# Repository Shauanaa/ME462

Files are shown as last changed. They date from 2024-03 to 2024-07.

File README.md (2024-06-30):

# 🏒 AirHockey and Micro Robot Project
istockphoto-1455938819-612x612 (1)

## 📚 Table of Contents
- [Project Abstract](#project-abstract)
- [AirHockey](#airhockey)
  - [Mechanical](#mechanical)
  - [Software](#software)
  - [Electronic](#electronic-airhockey)
- [Micro Robot](#micro-robot)
  - [Mechanical](#mechanical-1)
  - [Software](#software-1)
  - [Electronic](#electronic-microrobot)
- [How to Use the Code](#how-to-use-the-code)
- [Cautions](#cautions)
- [Contribution](#contribution)
- [License](#license)

## 🎯 Project Abstract
This project integrates an IoT-enabled air hockey table with a remotely controllable micro robot, creating diverse game scenarios. It showcases the fusion of mechanical engineering and software development to produce an interactive, entertaining system that reimagines classic gameplay through modern technology.

## 🏒 AirHockey

### Mechanical
The skeleton of the hockey table is constructed using a robust framework of aluminum extrusions, providing both strength and versatility. The main structure utilizes 20x20 mm sigma profile extrusions, offering an excellent balance of lightweight design and structural integrity. For enhanced stability and support, particularly along the edges, 20x40 mm extrusions are employed for the top bars, ensuring a rigid and durable frame.

The table's playing surface is crafted from high-quality plexiglass, chosen for its smooth texture and durability. This surface is meticulously perforated with 1 mm diameter holes arranged in a precise grid pattern. These holes serve a crucial function in the air hockey system, allowing for even air distribution across the entire playing field, which is essential for smooth puck movement.

To contain the gameplay and provide a clean aesthetic, the sides of the table are enclosed using medium-density fiberboard (MDF). This material was selected for its cost-effectiveness, ease of fabrication, and ability to be finished smoothly. The MDF side panels not only define the boundaries of the playing area but also contribute to the overall structural integrity of the table.

The entire assembly is held together using a combination of M5 and M6 screws and nuts. This hardware selection ensures a secure connection between all components while allowing for potential disassembly or modifications in the future. The use of standardized fasteners also simplifies maintenance and repairs.
This thoughtful design and material selection results in a hockey table that is not only sturdy and functional but also aesthetically pleasing and adaptable to various gameplay modifications or technological integrations.

There is a 'balcony' under the fans which is a housing for electronic components.

Our air hockey table is equipped with:

- High-powered air blowers
- High energy power supply for LEDS 
- Camera setup for object detection/tracking 
- LED lighting system for enhanced gameplay experience
- Remotely controllable side obstacles 

### Software
The software interfaces with 13 NeoPixel LED lines, strategically positioned and serially connected around the table. These LEDs are carefully wired and soldered to ensure stable connections between the power supply and each LED, enabling dynamic lighting effects during gameplay.

Complementing the LED system are mini electronic side obstacles, each equipped with its own controller. These obstacles are connected using jumper wires and breadboards, allowing for independent operation and easy modifications. This modular approach facilitates maintenance and potential future upgrades.

The combination of serially connected LED lines and independently controlled obstacles creates a flexible and responsive gaming platform, capable of supporting various gameplay scenarios and interactive features.

The air hockey system is powered by:

- Computer vision algorithms for real-time puck and leds
- Pip installable python code: `pip install air-hockey`
- ROS2 integrated software
  
### Electronics
- Please see the readme.md document [here](https://github.com/Shauanaa/ME462/blob/main/03_Codes/01_Air_Hockey/README.md)

## 🤖 Micro Robot

### Mechanical

The micro robot's chassis is additively manufactured using Creality 3D printers, offering a lightweight yet durable design. The chassis is engineered to house and protect all electronic components from external damage. Two strategically positioned motors control the robot's movement, enabling precise maneuvering and agile performance on the air hockey table. This combination of 3D-printed structure and dual-motor system results in a compact, resilient robot capable of swift and accurate movements during gameplay.

The micro robot features:

- Compact, agile design for quick movements
- Remotely Controllable motors
- Durable chassis to withstand impacts
- Modular design for easy maintenance and upgrades

### Software
The micro robot features two motors controlled by an ESP8266 microcontroller. An ESP-NOW controller enables remote control of the micro-robots, allowing for precise maneuvering. Additionally, the robot is equipped with a controllable propeller, enhancing its movement capabilities. This combination of dual-motor drive, wireless control, and propeller system creates a versatile and responsive robot, ideal for dynamic air hockey gameplay.

The micro robot is controlled by:

- You by publishing a message to the relevant topic, Raspberry Pi communicating with a controller ESP8266 via serial communication to send commands, controller ESP communicating with the micro robot ESP8266 using ESP-NOW protocol, and finally, the micro robot ESP applying the command.
### Electronics
- The schematics of the microrobot are provided as following:
  MicroRobotCircuit_bb (1)
- More technical drawing is as follows:
   MicroRobotCircuit_schem (1)

## 🖥️ How to Use the Code

Each entity in this project has its own readme file in details. HEre's the quick introduction version.
The folder structure is descripted as below:
```
project_root/
│
├── /03_Codes
│   └── 01_Air_Hockey/
│       ├── python_api/
│           └── microrobot_commander.py
│           ├── neopixel_controller.py
│       ├── ros2_ws/
│           └── src/air_hockey/
│               └── air_hockey/
│                   └── __init__.py
│                   ├── commander.py
│                   ├── commander_demo.py
│                   ├── localize.py
│                   ├── neopix.py
│                   ├── neopixel_demo.py
│               ├── config/
│                   └── cam_params.yaml
│               ├── resource/
│                   └── air_hockey
│               ├── test/
│                   └── test_copyright.py
│                   ├── test_flake8.py
│                   ├── test_pep257.py
│               ├── LICENSE
│               ├── package.xml
│               ├── setup.cfg
│               ├── setup.py
│           ├── 99-gpio.rules
│           ├── neopixel_test.py
│           ├── requirements.txt
│           ├── README.md
|       ├── qr_code_label_and_centroid_detection.py
│       └── camera_controller.py
│       └── Readme.md
│   └── 02_Micro_Robot/
|       ├── esp8266_espnow/
│           └── esp8266_espnow.ino
│       └── esp8266_espnow_agents/
│           └── esp8266_espnow_agents.ino
│           └── motor.ino
│       └── Readme.md

```

To get started with the AirHockey and Mini Robot project, follow these steps:

#### 1. Clone the Repository
```
git clone https://github.com/Shauanaa/ME462.git
cd ME462
```

#### 2. Install Dependencies
Ensure you have Python installed, then run:
```
pip install -e .
```

#### 3. Configure the System
##### For Python API:
  1) Install the requirements : `pip install neopixels serial numpy`
##### For ROS2:
  1) Create a venv: `python3 -m venv ~/ros2_venv`
  2) activate the venv `source ~/ros2_venv/bin/activate`
  3) install the required packages `pip install rclpy neopixels board serial`

#### 4. Run the Air Hockey System
##### For Python API:
  1) Install the requirements : `pip install neopixels serial numpy`
  2) Then simply run the codes: `python microrobot_commander.py` and `python neopixel_controller.py
##### For ROS2:
  1) navigate to the venv `cd ~/ros2_ws`
  2) Build your workspace: `colcon build`
  3) activate the venv `source ~/ros2_venv/bin/activate`
  
#### 5. Control the Micro Robot
Run the desired codew as folloing:`ros2 run air_hockey <package_name>`

#### 6. Additional Commands
- To segment the leds from the camera image : `python led_finder.py`
- To detect the QR code labels of the robots and positions of them: `python qr_code_label_and_centroid_detection.py`
- To test neopixels in ROS2: `python 03_Codes/01_Air_Hockey/ros2_ws/src/air_hockey/air_hockey/neopixel_demo.py`
- To test commander tools in ROS2: `python 03_Codes/01_Air_Hockey/ros2_ws/src/air_hockey/air_hockey/commander_demo.py`

For more detailed instructions and troubleshooting, please reach out the contributors and open an issue.

## ⚠️ Cautions

When using this system, please be aware of the following:
- 🛑PLEASE UNPLUG ALL OF THE CABLES WHILE OPENING THE ELECTRONIC DEVICES OF THE AIRHOCKEY TABLE🛑

- The IP address of the Raspberry Pi changes when connecting to different networks. Always ensure you have the correct IP address before attempting to connect to the Raspberry Pi.
- Do not forget to change the shebang of the ROS2 codes such that it points to a python interpreter on your system.

## 🤝 Contribution

We welcome contributions from the community! If you'd like to contribute, please follow these steps:

1. Fork the repository
2. Create your feature branch (`git checkout -b feature/AmazingFeature`)
3. Commit your changes (`git commit -m 'Add some AmazingFeature'`)
4. Push to the branch (`git push origin feature/AmazingFeature`)
5. Open a Pull Request

## 📄 License

This project is licensed under the MIT License - see the [LICENSE.md](LICENSE.md) file for details.

---

<p align="center">
  Made with ❤️ by the AirHockey and Mini Robot Team:
  Berk Ünlü, 
  Sait Burak Yücekaya,
  Yunus Çınar Kızıltepe,
  Tan Çağatay Acar,
  Doğukan Özoğul,
  Candaş Uysal
</p>

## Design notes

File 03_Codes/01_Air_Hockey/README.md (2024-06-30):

# Air Hockey
The codes that run on the Raspberry Pi of the air hockey table. The Raspberry Pi has Ubuntu 24.04 Server running.

### Python API
#### NeoPixel Controller
Python library to control NeoPixels of the air hockey table. Example usage:
```
from air_hockey.neopixel_controller import NeoPixel_Controller

controller = NeoPixel_Controller()

controller.fill((100, 0, 255)) # Set every pixel the specified rgb color.

controller.setFromFlatArray([(100, 0, 255),(80, 20, 255),(60, 40, 255),(40, 60, 255),(20, 80, 255),(0, 100, 255)]) # Sets pixels from array in order.
```
#### Commander
Python library to control micro robots wirelessly. Desk fan example:
```
from air_hockey.microrobot_commander import Commander
import time,math

commander = Commander()
theta = 0
while True:
    mag = 80*math.sin(theta)
    commander.send(1, int(mag), int(-mag), 200)
    theta = theta + 0.15
    time.sleep(0.1)
```
#### Localization
Python library to obtain pose data of micro robots. Example usage:
```
from air_hockey.localize_microrobot import Locator
import time

locator = Locator()
while True:
    print(locator.getPoses())
    time.sleep(0.5)
```
### ROS2 Workspace
This workspace contains the `air_hockey` package that includes the codes to be able to control LEDs of the table, control micro robots and obtain the pose information of these robots.
#### NeoPixels
The server code is run by the command `ros2 run air_hockey neopixel`. This code listens to 2 topics called `/NeoPixel/array` and `/NeoPixel/fill`. They show the given rgb array or all LEDs display a RGB color, respectively. Array elements are 8-bit unsigned integers and mimic OpenCV Numpy Array structure. Fill topic communicates with `std_msgs/msg/ColorRGBA` and expects float values that range from 0.0 to 1.0.
#### Commander
The commander code is run by the command `ros2 run air_hockey commander`. This code listens to `/agent_0/cmd` and `/agent_1/cmd` topics. These topics expect 3 integer values: left motor power, right motor power, and fan motor power, respectively. These values are in ranges {[-255,255],[-255,255],[0,255]}. This code then communicates with the commander ESP that controls the micro robots.
#### Localization
The localization code is run by the command `ros2 run air_hockey localization`. This code uses the camera to detect the April Tags of the micro robots and calculate their poses. Once detected, the pose data are published to `/agent_x/pose` topic, where x changes with the detected tag id.

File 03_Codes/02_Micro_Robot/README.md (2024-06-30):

# Micro Robot
This robot is a small, remote controllable, heavy robot that is also equiped with a fan. Controlling these robots remotely is not explained here and instead discussed in [Air Hockey Section](/03_Codes/01_Air_Hockey).

### Mechanics
The mechanical design of the robots are completed with Autodesk Fusion. Therefore, Fusion Archive Files and stls are included in [this folder](/04_CAD_Files/02_Micro_Robot).
#### April Tags
These robots can have April Tags on them to have localization features. Tag standart 36h11 is used with size 56 mm. You can use [this website](https://chaitanyantr.github.io/apriltag.html) for easy tag generation. You should use tags with ids the same with the agents'.

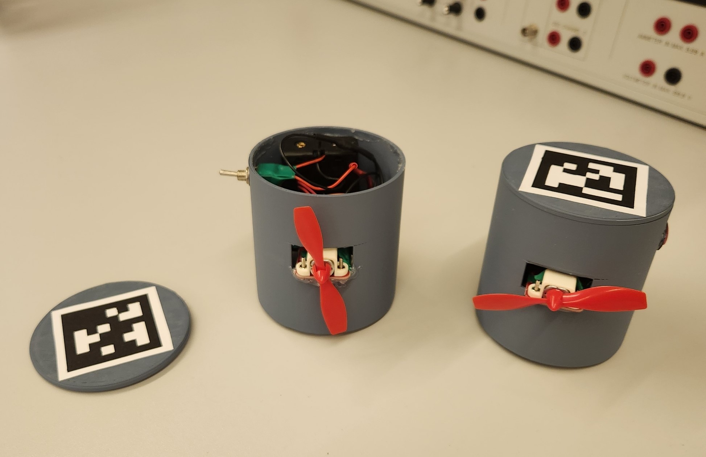
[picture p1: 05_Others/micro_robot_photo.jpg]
Micro Robots


### Electronics
The electonics are fitted in such a small compartment that we need the smallest components and modules to construct this robot. The list of the components used to build one robot is provided [here](/04_CAD_Files/02_Micro_Robot/MicroRobotCircuit_bom.html):

* [L9110 Fan Module](https://www.robolinkmarket.com/l9110-fan-modulu)
* [2x70 RPM 12mm Micro Motor](https://www.robotistan.com/6v-12mm-70-rpm-reduktorlu-dc-motor)
* [TB6612FNG Motor Controller](https://www.robotistan.com/tb6612fng-step-motor-surucu-dc-motor-sucuru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)
* [Lolin (Wemos) Mini Clone ESP8266 Card](https://www.robolinkmarket.com/esp8266-nodemcu-mini-gelistirme-karti)
* [2A Mini Buck Converter](https://www.robolinkmarket.com/2a-mini-ayarlanabilir-voltaj-dusurucu-regulator-karti)
* [2x18650 Li-ion Battery](https://www.robolinkmarket.com/power-xtra-px18650-25p-37v-2500-mah-li-ion-sarjli-pil-12c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)
* [2S 18650 Battery Bed](https://www.robolinkmarket.com/2li-18650-pil-yuvasi-lityum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)
* On/Off Switch
* Female Headers and Wires

The pin assignments are present in the codes provided. Also a fritzing circuit drawing can be found in [CAD folder](/04_CAD_Files/02_Micro_Robot).

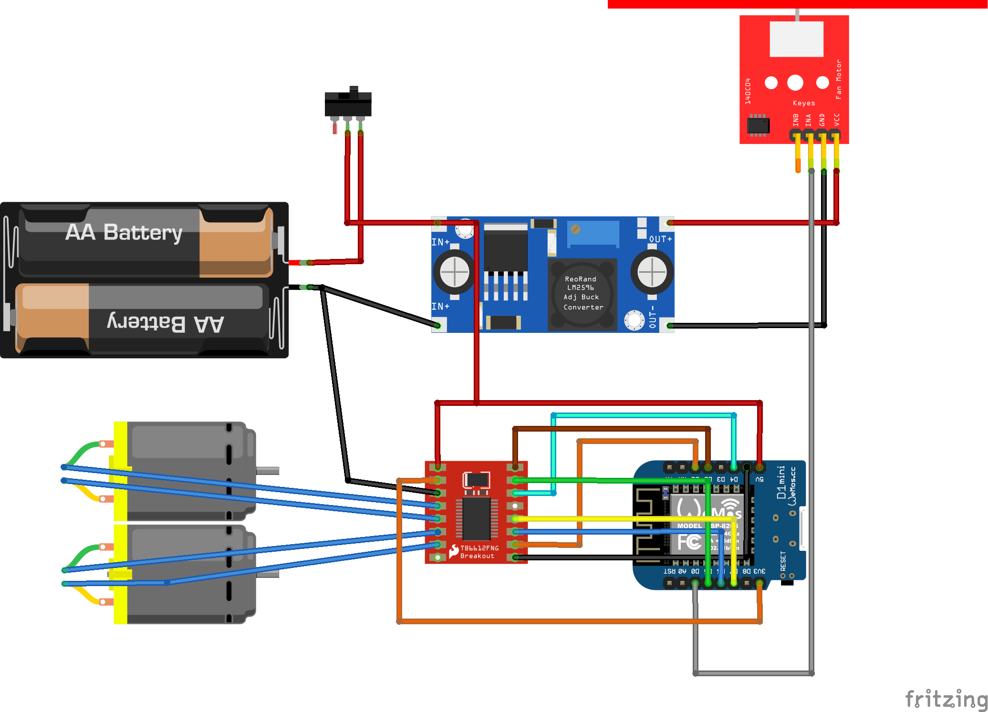
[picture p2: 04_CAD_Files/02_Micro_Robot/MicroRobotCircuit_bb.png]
Circuit Drawing


### Software
The ESP8266 microcontroller is coded with Arduino IDE. 2 codes are present, `esp8266_espnow_agents` code is for the robots. The `AGENT_ID` should be unique for each robot that will operate simultaneously. `esp8266_espnow` code is for the controller ESP8266 that is used to communicate with the robots. This controller should be connected to your PC or the Raspberry Pi via a USB cable to be able to control the robots. `MAX_AGENTS` parameter dictates the maximum number of robots to be controlled simultaneously. Also, the robots should have ids lower than this value!
#### Registering New Agents
In order for commander ESP to search and find new agents, first the new agent robots should be opened, then the commander ESP needs to be reseted. After this operation, commander saves the new agents' MAC addresses in its EEPROM so it remembers them until a different is registered with the same id.

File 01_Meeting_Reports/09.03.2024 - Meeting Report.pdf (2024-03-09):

[Air Hockey - Micro Robot Group] ME462 - TOPLANTI 1
2023-2024 BAHAR

9 Mart 2024

## 1 GUNDEM ¨

Bu dok¨ uman 9 Mart 2024 tarihinde Air Hockey - Micro Robot proje grubu arasında yapılan ¨
toplantıda tartıs¸ılan konuları ozetlemek ¨ | uzere yazılmısţır. ¨

Toplantının gundem basļıkları s¸u sȩkilde sıralanabilir. ¨

1. Mock-up mekanik dizaynın tartıs¸ılması ve gelisţirilmesi
2. Dizayn ozelinde olus¸abilecek problemlerin tespiti ve tartıs¸ılması ¨
3. Proje için ilerleyen safhalardaki isterlerin tespiti
4. Proje bazlı gorevlendirme tanımlamalarının netlesţirilmesi ve alt grupların belirlenmesi ¨
5. Alt gruplar arası iletis¸imi saglamak ˘ | uzere bir koordinat ¨ | or ¨ un seçilmesi ¨
6. Karalasţırılan grupların is¸bas¸ı yapması

### 1.1 Mock-Up Mekanik Dizaynın Tartıs¸ılması ve Gelisţirilmesi

05.03.2024 tarihinde ROMER’de yapılan toplantının ardından deneme amacļı bir CAD modelinin
tasarımı yapılmısţır ve tum¨ | uyelerin katılımıyla geli ¨ | sţirilmisţir. İlk modelimizin eksikleri tespit
edilmis¸ ve moduler tasarımın modele nasıl entegre edilebilece ¨ | gi tartı ˘ | s¸ılmısţır. Çizilen modele gore ¨
basitcȩ tahta kullanılarak pleksi levhanın sabitlenecegi bir platform ˘ | uretilmisţir. ¨

Buna ek olarak, tahtadan yapılan model ile kars¸ılasţırılmak uzere CAD modelimizin de 3D ¨
baskı yontemiyle elde edilmesi kararla ¨ | | | | sţırılmısţır. Bu kararın arkasındaki ana neden 3D parçamızın
dıs¸ında kullanabilecegimiz materyallerin duvarlarının hava ka ˘ | çırma karakteristigini test etmektedir. ˘
Baskı alabilmemiz ise farklı buy¨ ukl ¨ ukte ve sıklıkta deliklerin hava akı ¨ | s¸ındaki etkisinin belirlenmesi
de mumk ¨ | un g ¨ | oz¨ ukmesinden ¨ | ot ¨ ur ¨ u dizayn s ¨ | urecinde avantaj icȩrmektedir. ¨

### 1.2 Dizayn Ozelinde Olus¸abilecek Problemlerin Tespiti ve Tartıs¸ılması ¨

Bu noktada kars¸ılasţıgımız hatalardansa mod ˘ | uler dizayn kullanıldı ¨ | gı senaryoda olu ˘ | s¸abilecek
muhtemel problemler dus¸¨ un¨ ulm¨ us¸ ve bunların nasıl minimize edilebilece ¨ | gi tartıs¸ılmısţır. ˘
Genellikle nihai dizaynımızdaki yerles¸im problemleri (arenamızı sekizgen du¨s¸und ¨ | u¨gŭm¨ uzde ¨
kenarlara oturtmak istedigimiz istasyonların yerle ˘ | s¸imleri) ele alınmısţır. Burada mekanik ve elek-
tronik çoz¨ umler d ¨ | u¨s¸un¨ ulm¨ u¨s¸ ve birkaç fikir elde edilmisţir. Buna ek olarak istasyonların kenarlarda
olması planlanan sigma profillere monte etmek yerine arenanın içine entegre edilip edilemeyecegi ˘
dus¸¨ un¨ ulm¨ us¸, ve karar daha sonraki toplantılarda finalize etmek ¨ | uzere ertelenmisţir. ¨

ME462 - Mechatronic System Design

Arenanın elektronik dizaynı ile ilgili olarak ise olası iletis¸im protokolleri (I2C, USB Serial ve WiFi) ve bunların entegrasyonu tartıs¸ılmısţır. Çıkabilecek problemler, avantajlar ve dezavantajlar
goz¨ on¨ une alınarak mod ¨ | uler mekanik dizayn i ¨ | çin detaylı arasţırmaların yapılmasına karar verilmisţir.
Bir diger ˘ | oenmli dizayn kriteri olan g ¨ | u¨ç aktarım istasyonunun nasıl yapılabilecegi ile ilgili fikir ˘
alıs¸veris¸i yapılmısţır.

### 1.3 Proje İçin İlerleyen Safhalardaki İsterlerin Tespiti

Bu konuda gelisţirmek istedigimiz sistemimiz için gerekli isterler bulunmaya çalıs¸ılmısţır. ˘

1.4 Proje Bazlı Gorevlendirme Tanımlamalarının Netle ¨ | sţirilmesi ve Alt Gru-

### pların Belirlenmesi

Projenin basļangıcından itibaren belirsiz ve duzensiz olan g ¨ | orevlendirmeleri netle ¨ | sţirmek amacıyla
grup uyelerinin de ¨ | çalıs¸mak istedigi konular da g ˘ | oz¨ on¨ unde bulundurularak proje i ¨ | çinde alt takımlar
olusţurulmusţur.
Bu alt grupları olusţurmamızın temel amacı, her uyenin ana sorumlu olarak ¨ | çalıs¸acagı alanları ˘
spesifik olarak belirleyerek ileride kars¸ılas¸abilecegimiz olası problemleri en az hasarla atlatabilmek- ˘
tir. Ustelik bu sayede g ¨ | orev da ¨ | gılımının proje s ˘ | uresince e ¨ | s¸it dagılımı ama ˘ | cļanmaktadır. Ancak bu
ozelles¸me farklı alanların birbirinden habersiz bir sȩkilde çalıs¸aca ¨ | gı sȩklinde algılanmamalıdır. ˘

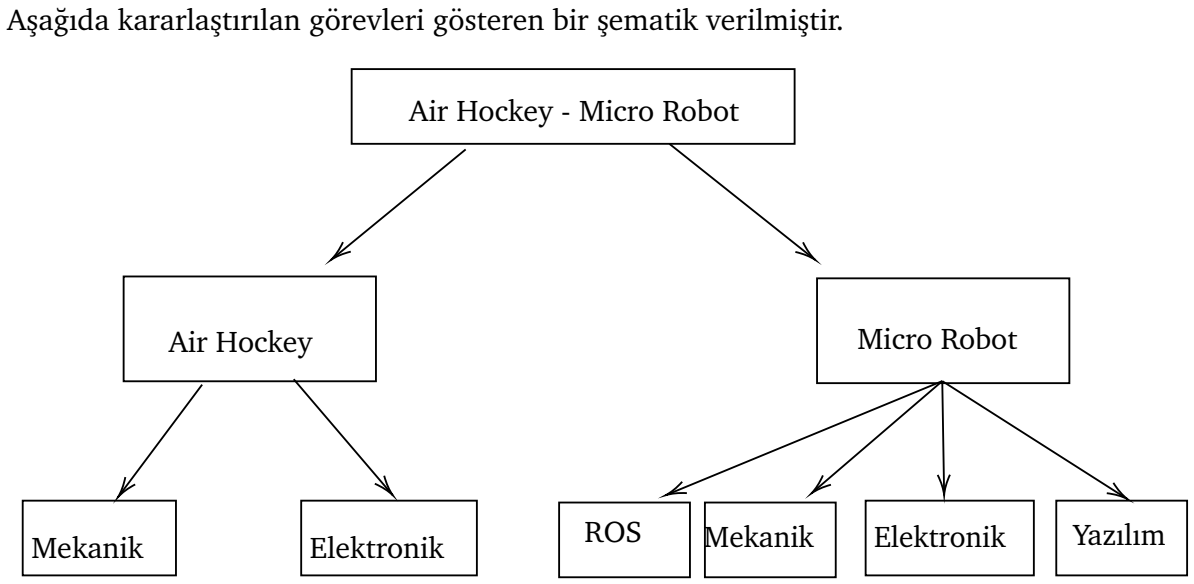
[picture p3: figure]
As¸agıda kararlasţırılan g ˘; orevleri g ¨; osteren bir sȩmatik verilmisţir. ¨; Air Hockey - Micro Robot; Air Hockey; Micro Robot; Mekanik; Elektronik; ROS; Yazılım

Candas¸

Çınar

Sait

Dogukan ˘ | Dogukan ˘
| Çınar

Berk

Sait

Sait

Candas¸

Tan

Dogukan ˘

Tan

2

ME462 - Mechatronic System Design

1.5 Alt Gruplar Arası İletis¸imi Saglamak ˘ | Uzere Bir Koordinat ¨ | or¨ un Seçilmesi ¨
Grupların ayrılması ne kadar odaklanma seviyesini ne kadar arttırsa da yarattıgı ileti ˘ | s¸imsel
sıkıntılar onemli bir dezavantaj da i ¨ | cȩrmektedir. Bu negatif etkileri minimize etmek ve her-
hangi bir kopukluk yas¸amamak uzere ¨ | uyelerden birinin gruplar arası koordinasyonu s ¨ | urd ¨ urmesi ¨
amacļanmısţır. Uyelerin ders programları ve yo ¨ | gunlukları tam olarak bilinmedi ˘ | ginden koordinat ˘ | ore ¨
daha ileri bir tarihte karar verilecektir.

### 1.6 Karalasţırılan Grupların İs¸bas¸ı Yapması

Tum hushuslar tartı ¨ | s¸ıldıktan sonra yapılacak en etkili yontemin en kısa s ¨ | urede elle tutulur bir ¨
model elde etmek ve projemizde kullanılacak kaynakların hazırlanması oldugu konusunda t ˘ | um¨
uyeler hemfikirdir. Bu sebeple, bu toplantı sonrasında iki ayrı gruba b ¨ | ol ¨ un¨ ulm¨ | u¨s¸ ve kaynakların
hazırlanmasına basļanılmısţır.
Bir grup yukarıda bahsedildigi ˘ uzere de mekanik olarak ¨ | uretimle ba ¨ | sļamıs¸ ve iki ayrı materyalden
model elde edilmeye çalıs¸ılmısţır.
Diger grup ise Micro Robot kolunda kullanılacak Raspberry Pi 4 mikrokontrolc ˘ | us ¨ un¨ un kamera ¨
entegrasyonu konusunda çalıs¸malarda bulunmusţur. Bu çalıs¸malarda kameranın Raspberry Pi 4
mikrokontrolcus ¨ un¨ un i ¨ sļetim sistemi Ubuntu Jammy Jellyfish 22.04 yardımıyla kontrolu denenmi ¨ | sţir.
Son olarak da ROS sisteminin mikrokontrolcude çalıs¸ıp çalıs¸madı ¨ | gı g ˘ ozlenmisţir. ¨

3

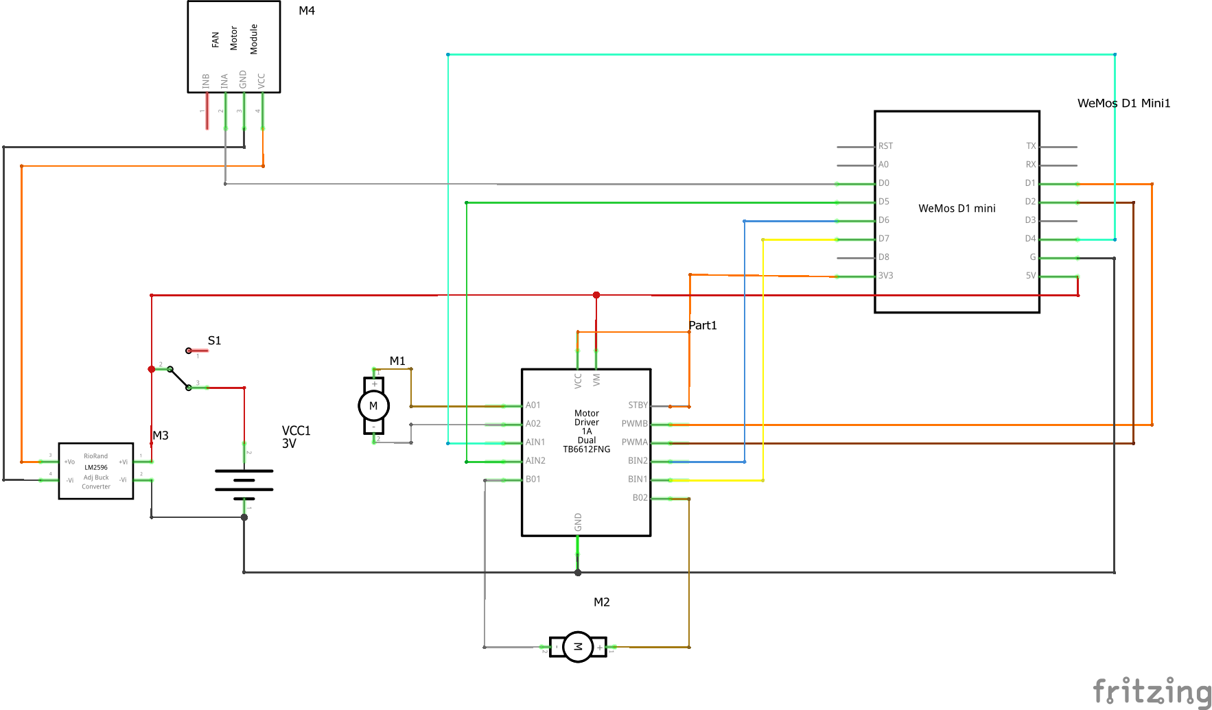
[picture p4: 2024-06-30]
04_CAD_Files/02_Micro_Robot/MicroRobotCircuit_schem.png

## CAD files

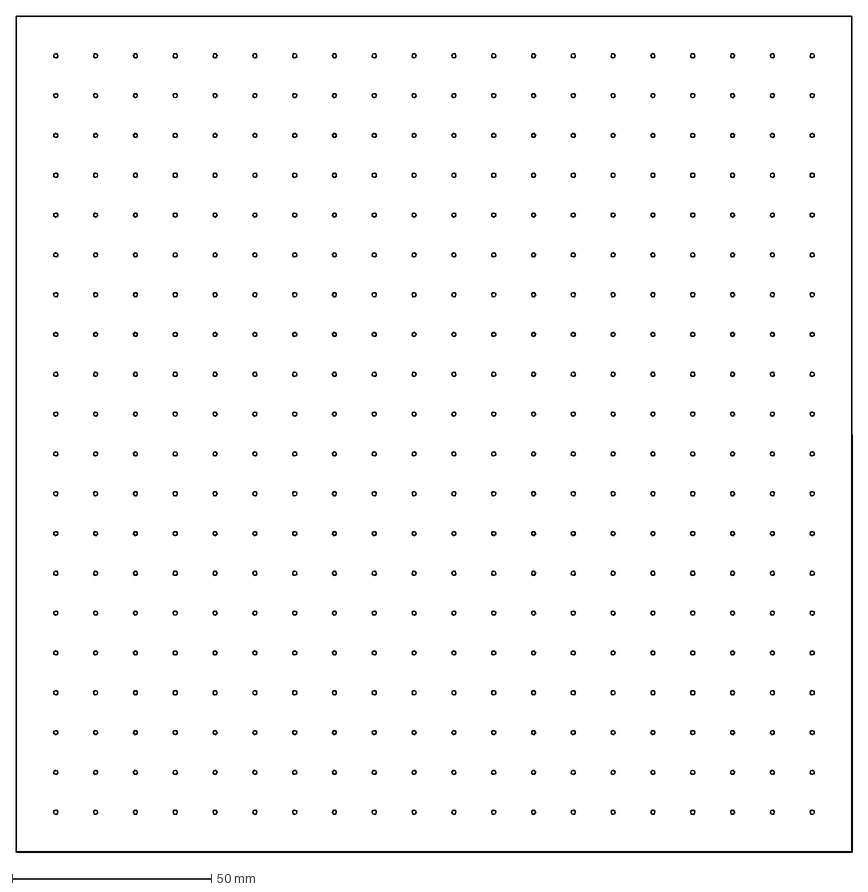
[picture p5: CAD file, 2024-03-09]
04_CAD_Files/01_Air_Hockey/dxf files/AH 210mmx210mm R1mm d10mm.dxf
210.0 x 210.0 mm

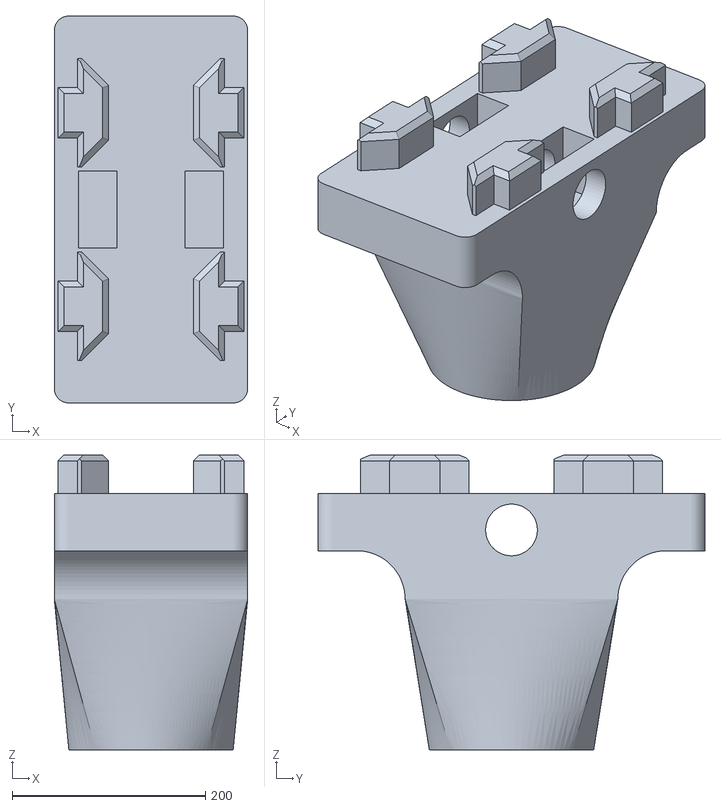
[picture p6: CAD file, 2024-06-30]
04_CAD_Files/01_Air_Hockey/stl files/extrusion ayak connect v3.stl
200.0 x 400.0 x 305.0

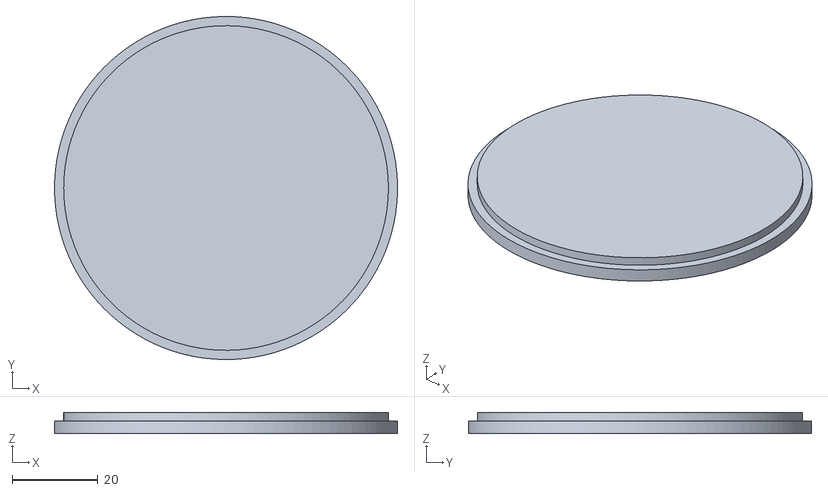
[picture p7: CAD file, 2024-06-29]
04_CAD_Files/02_Micro_Robot/micro robot lid.stl
80.0 x 80.0 x 5.00

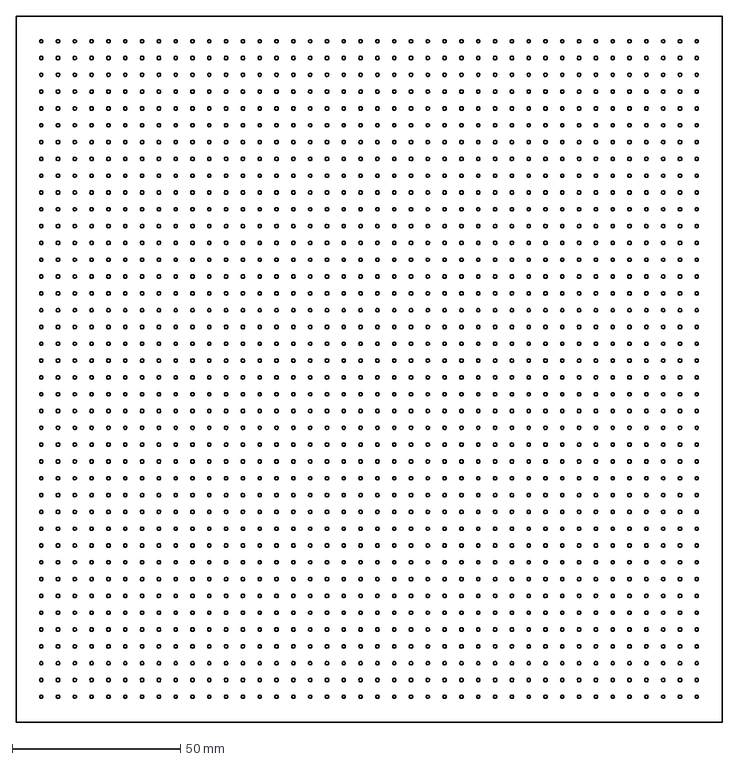
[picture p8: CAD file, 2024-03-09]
04_CAD_Files/01_Air_Hockey/dxf files/AH 210mmx210mm R1mm d5mm.dxf
210.0 x 210.0 mm

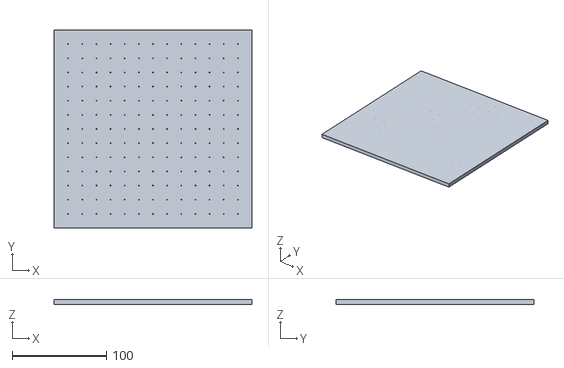
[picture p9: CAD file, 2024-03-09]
04_CAD_Files/01_Air_Hockey/stl files/AH 210mmx210mm R1mm d15mm.stl
210.0 x 210.0 x 5.00

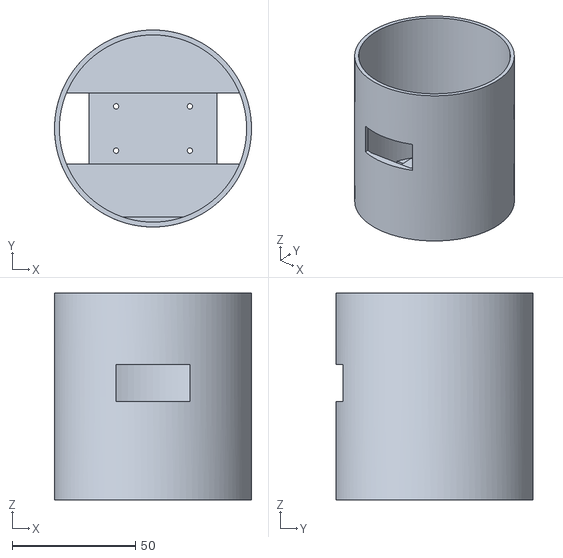
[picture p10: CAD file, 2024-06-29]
04_CAD_Files/02_Micro_Robot/micro robot body.stl
80.0 x 80.0 x 84.0

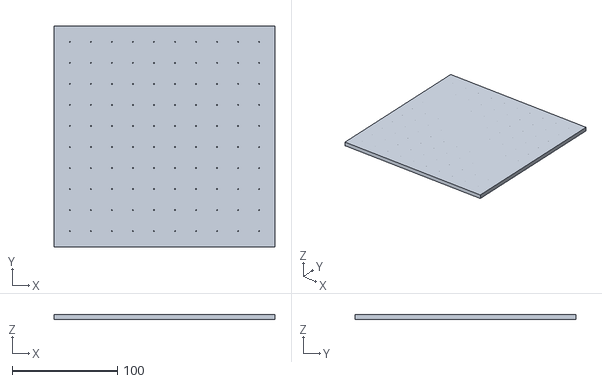
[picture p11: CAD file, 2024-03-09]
04_CAD_Files/01_Air_Hockey/stl files/AH 210mmx210mm R1mm d20mm.stl
210.0 x 210.0 x 5.00

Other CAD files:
04_CAD_Files/01_Air_Hockey/dxf files/AH 210mmx210mm R1mm d15mm.dxf
04_CAD_Files/01_Air_Hockey/dxf files/AH 210mmx210mm R1mm d20mm.dxf
04_CAD_Files/02_Micro_Robot/micro robot body.f3d
04_CAD_Files/02_Micro_Robot/micro robot lid.f3d

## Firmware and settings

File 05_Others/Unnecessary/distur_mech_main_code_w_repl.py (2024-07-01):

import time
import sys
import select
import stepper
from machine import Pin, Timer
from usys import stdin
from uselect import poll

class StepperMotorControl:
    def __init__(self):
        self.puck_motor = self.initialize_motor(10, 11, 12, 13)
        self.wall_motor = self.initialize_motor(2, 3, 4, 5)
        self.spin_motor = self.initialize_motor(6, 7, 8, 9)
        self.spio_motor = self.initialize_motor(18, 19, 20, 21)
        
        self.poll_obj = select.poll()
        self.poll_obj.register(sys.stdin, select.POLLIN)
        
    def initialize_motor(self, in1, in2, in3, in4):
        motor = stepper.HalfStepMotor.frompins(in1, in2, in3, in4)
        motor.reset()
        return motor

    def step_motor(self, motor, angle):
        motor.step_until_angle(angle)
        motor.step_until_angle(0)

    def stop_motor(self, motor):
        motor.reset()
    
    def control_motor(self, motor, working_flag):
        setattr(self, working_flag, True)
        while getattr(self, working_flag):
            self.step_motor(motor, 30)
            res = self.poll_obj.poll()
            ch = res[0][0].read(1)
            if ch == '9':
                setattr(self, working_flag, False)
                self.stop_motor(motor)
                break

    def control_dual_motors(self, motor1, motor2, working_flag1, working_flag2):
        setattr(self, working_flag1, True)
        setattr(self, working_flag2, True)
        while getattr(self, working_flag1) and getattr(self, working_flag2):
            self.step_motor(motor1, 30)
            self.step_motor(motor2, 30)
            res = self.poll_obj.poll()
            ch = res[0][0].read(1)
            if ch == '9':
                setattr(self, working_flag1, False)
                setattr(self, working_flag2, False)
                self.stop_motor(motor1)
                self.stop_motor(motor2)
                break

    def run(self):
        try:
            while True:
                res = self.poll_obj.poll()
                ch = res[0][0].read(1)
                if ch == '1':
                    self.control_motor(self.puck_motor, 'puck_motor_working')
                elif ch == '2':
                    self.control_motor(self.wall_motor, 'wall_motor_working')
                elif ch == '3':
                    self.control_motor(self.spin_motor, 'spin_motor_working')
                elif ch == '4':
                    self.control_motor(self.spio_motor, 'spio_motor_working')
                elif ch == '12':
                    self.control_dual_motors(self.puck_motor, self.wall_motor, 'puck_motor_working', 'wall_motor_working')
                elif ch == '13':
                    self.control_dual_motors(self.puck_motor, self.spin_motor, 'puck_motor_working', 'spin_motor_working')
                elif ch == '14':
                    self.control_dual_motors(self.puck_motor, self.spio_motor, 'puck_motor_working', 'spio_motor_working')
                elif ch == '23':
                    self.control_dual_motors(self.wall_motor, self.spin_motor, 'wall_motor_working', 'spin_motor_working')
                elif ch == '34':
                    self.control_dual_motors(self.spin_motor, self.spio_motor, 'spin_motor_working', 'spio_motor_working')
                elif ch == '9':
                    break
        except KeyboardInterrupt:
            print("Control interrupted by user.")
def print_air_hockey_table():
    table = """
    +-----------------------------------------+
    |                   .                     |
    |                                         |
    |                   |                     |
    |                   |                     |
    |                   |                     |
    |                   |                     |
    |                   |                     |
    |                   |                     |
    |                   |                     |
    |                   |                     |
    |                   |                     |
    |                   |                     |
    |                   |                     |
    |                   .                     |
    +-----------------------------------------+
    """
    print(table)
    
def repl():
    controller = StepperMotorControl()
    print("*** WELCOME TO AIR HOCKEY ***")
    print_air_hockey_table()
    print("The controlling mechanism of the disturbance mechanisms are as follows":)
    print("To power up the motors, you should enter the corresponding number for each motor.")

    print("Enter commands to control the motors. Type 'exit' to quit.")
    
    try:
        while True:
            command = input(">>> ")
            if command == 'exit':
                break
            else:
                sys.stdin = StringIO(command)
                controller.run()
    except KeyboardInterrupt:
        print("\nExiting REPL.")
    finally:
        sys.stdin = sys.__stdin__

if __name__ == "__main__":
    repl()

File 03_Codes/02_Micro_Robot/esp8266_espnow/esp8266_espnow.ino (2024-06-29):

#include <EEPROM.h>
#include <ESP8266WiFi.h>
#include <espnow.h>

//kanal belirliyoruz alıcı ve verici aynı kanalda olmalı 
#define CHANNEL 1
#define MAX_AGENTS 10

uint8_t agents[MAX_AGENTS][6];
bool agents_present[MAX_AGENTS];
uint8_t buffer[20];

void setup ()
{
  buffer[10] = '\0';
  Serial.begin(115200);
  Serial.print("\nStarting WiFi!\nESP Board MAC Address:  ");
  Serial.println(WiFi.macAddress());
  WiFi.mode(WIFI_STA);
  esp_now_init();
  esp_now_set_self_role(ESP_NOW_ROLE_CONTROLLER);
  //esp_now_register_send_cb(OnDataSent);
  EEPROM.begin(MAX_AGENTS*7);
  LoadFromEEPROM();
  ScanForSlave();
  SaveToEEPROM();
}

void OnDataSent(uint8_t *mac_addr, uint8_t status ) {
  Serial.printf("Sent: %d\n", status);
}

void loop(){
  if(Serial.available() > 0){
    //Serial.printf("Received:\n");
    if(Serial.readBytesUntil('\n', buffer, 14) == 13){
      //buffer[9] = '\0';
      //Serial.printf("%s\n", buffer);
      for(int agent_id = 0; agent_id < MAX_AGENTS; agent_id++){
        if(('a'+agent_id == buffer[0]) && (agents_present[agent_id] == true)){
          buffer[13] = '\n';
          //Serial.printf("%s",buffer);
          esp_now_send(agents[agent_id], buffer, 14);
        }
      }
    }
  }
}

void LoadFromEEPROM(){
  Serial.println("--------------------------");
  Serial.println("Loaded from EEPROM:");
  for(int i = 0; i < MAX_AGENTS;i++){
    for(int j = 0; j < 6;j++){
      EEPROM.get(j+i*6, agents[i][j]);
    }
  }
  for(int i = 0; i < MAX_AGENTS;i++){
    EEPROM.get(MAX_AGENTS*6 + i, agents_present[i]);
    if(agents_present[i]){
      Serial.printf("Agent %d MAC: %02x:%02x:%02x:%02x:%02x:%02x!\n", i, agents[i][0], agents[i][1], agents[i][2], agents[i][3], agents[i][4], agents[i][5]);
    }
  }
  Serial.println("--------------------------");
}

void SaveToEEPROM(){
  Serial.println("--------------------------");
  Serial.println("Saved to EEPROM:");
  for(int i = 0; i < MAX_AGENTS;i++){
    for(int j = 0; j < 6;j++){
      EEPROM.put(j+i*6, agents[i][j]);
    }
  }
  for(int i = 0; i < MAX_AGENTS;i++){
    EEPROM.put(MAX_AGENTS*6 + i, agents_present[i]);
    if(agents_present[i]){
      Serial.printf("Agent %d MAC: %02x:%02x:%02x:%02x:%02x:%02x!\n", i, agents[i][0], agents[i][1], agents[i][2], agents[i][3], agents[i][4], agents[i][5]);
    }
  }
  EEPROM.commit();
  Serial.println("--------------------------");
}

void ScanForSlave() 
{
  int16_t scanResults = WiFi.scanNetworks(); // Scan only on one channel
  for (int i = 0; i < scanResults; ++i) {
    // Print SSID and RSSI for each device found
    String SSID = WiFi.SSID(i);
    String BSSIDstr = WiFi.BSSIDstr(i);
    for(int agent_id = 0; agent_id < MAX_AGENTS; agent_id++){
      String agent_name("AGENT_");
      agent_name.concat(agent_id);
      if (SSID.compareTo(agent_name) == 0){
        int mac[6];
        if ( 6 == sscanf(BSSIDstr.c_str(), "%x:%x:%x:%x:%x:%x",  &mac[0], &mac[1], &mac[2], &mac[3], &mac[4], &mac[5] ) ) {
          for (int j = 0; j < 6; ++j ) {
            agents[agent_id][j] = (uint8_t) mac[j];
          }
        }
        esp_now_add_peer(agents[agent_id],ESP_NOW_ROLE_SLAVE,1,NULL,0);
        agents_present[agent_id] = true;
        Serial.printf("Agent %d found with MAC: %02x:%02x:%02x:%02x:%02x:%02x!\n", agent_id, agents[agent_id][0], agents[agent_id][1], agents[agent_id][2], agents[agent_id][3], agents[agent_id][4], agents[agent_id][5]);
      }
    }
  }
}

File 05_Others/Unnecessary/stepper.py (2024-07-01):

# Rui Santos & Sara Santos - Random Nerd Tutorials
# Complete project details at https://RandomNerdTutorials.com/raspberry-pi-pico-stepper-motor-micropython/
# Forked from: https://github.com/larsks/micropython-stepper-motor/blob/master/motor.py

import machine
import time

class Motor:
    stepms = 10

    # Do be defined by subclasses
    maxpos = 0
    states = []

    def __init__(self, p1, p2, p3, p4, stepms=None):
        self.pins = [p1, p2, p3, p4]

        if stepms is not None:
            self.stepms = stepms

        self._state = 0
        self._pos = 0

    def __repr__(self):
        return '<{} @ {}>'.format(
            self.__class__.__name__,
            self.pos,
        )

    @property
    def pos(self):
        return self._pos

    @classmethod
    def frompins(cls, *pins, **kwargs):
        return cls(*[machine.Pin(pin, machine.Pin.OUT) for pin in pins],
                   **kwargs)

    def reset(self):
        self._pos = 0

    def _step(self, dir):
        state = self.states[self._state]

        for i, val in enumerate(state):
            self.pins[i].value(val)

        self._state = (self._state + dir) % len(self.states)
        self._pos = (self._pos + dir) % self.maxpos

    def step(self, steps):
        dir = 1 if steps >= 0 else -1
        steps = abs(steps)

        for _ in range(steps):
            t_start = time.ticks_ms()

            self._step(dir)

            t_end = time.ticks_ms()
            t_delta = time.ticks_diff(t_end, t_start)
            time.sleep_ms(self.stepms - t_delta)

    def step_until(self, target, dir=None):
        if target < 0 or target > self.maxpos:
            raise ValueError(target)

        if dir is None:
            dir = 1 if target > self._pos else -1
            if abs(target - self._pos) > self.maxpos/2:
                dir = -dir

        while True:
            if self._pos == target:
                break
            self.step(dir)

    def step_until_angle(self, angle, dir=None):
        if angle < 0 or angle > 360:
            raise ValueError(angle)

        target = int(angle / 360 * self.maxpos)
        self.step_until(target, dir=dir)
        
    def step_degrees(self, degrees):
        if degrees < 0 or degrees > 360:
            raise ValueError("Degrees should be between 0 and 360")

        steps_to_take = int(degrees / 360 * self.maxpos)

        self.zero()  # Ignore the current position, start from zero
        self.step(steps_to_take)

class FullStepMotor(Motor):
    stepms = 5
    maxpos = 2048
    states = [
        [1, 1, 0, 0],
        [0, 1, 1, 0],
        [0, 0, 1, 1],
        [1, 0, 0, 1],
    ]


class HalfStepMotor(Motor):
    stepms = 3
    maxpos = 4096
    states = [
        [1, 0, 0, 0],
        [1, 1, 0, 0],
        [0, 1, 0, 0],
        [0, 1, 1, 0],
        [0, 0, 1, 0],
        [0, 0, 1, 1],
        [0, 0, 0, 1],
    ]

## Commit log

2024-06-29 Added microrobot stuff
    [micro robot body.f3d, micro robot body.stl, micro robot lid.f3d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]
2024-06-29 Added Raspberry Pi ROS2 codes
2024-06-30 Added circuit design files
    [MicroRobotCircuit.fzz]
